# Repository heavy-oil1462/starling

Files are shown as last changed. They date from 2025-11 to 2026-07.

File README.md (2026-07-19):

# Starling

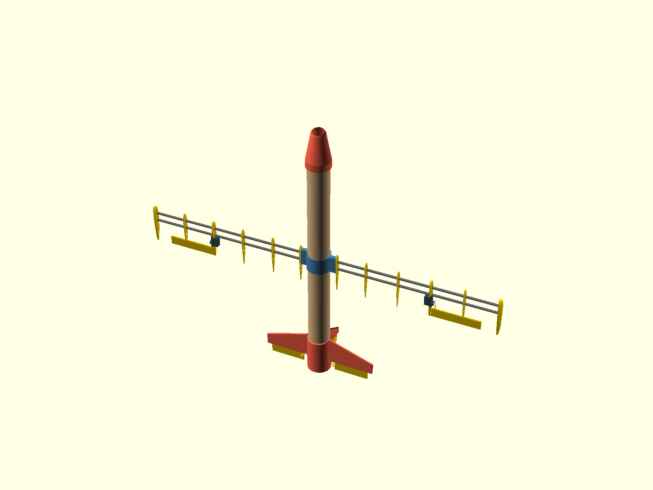
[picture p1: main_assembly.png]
Current assembly


**Starling** is an open-source, cheap, quick-to-assemble RC plane built around a paper tube. The fuselage is a ~53 mm postal tube; everything structural that isn't the tube is 3D printed or off the shelf. It is deliberately **not** built to last — it's built to be so cheap and fast to assemble that it can be treated as single-use for whatever job it's needed for (painting the tube adds some weather resistance if you want more than one flight).

## Project goals

1. **Cheap and expendable** — paper-tube fuselage, printed joints, hobby-grade electronics. Losing the airframe should not hurt.
2. **Payload modularity** — payloads ride *inside* the tube, not bolted to the outside. The tube is one uncut length, cut to suit the mission; a printed adapter wraps the payload so it slides into the tube bore (~47 mm) and can be positioned anywhere along it. A payload that is already a cylinder of the right diameter needs no adapter at all.
3. **Movable wing** — the wing mount slides along the tube to re-trim CG for whatever payload is fitted.
4. **Quick assembly** — parts slide over/into the tube; the goal is field-assembly speed, not workshop craftsmanship.
5. **ArduPilot brain** — flight controller config will live in this repo alongside the CAD (planned).

## Airframe

| Part | File | Notes |
|---|---|---|
| Fuselage | (bought, not printed) | 50 mm-class paper/postal tube, ~53 mm OD |
| Nose cone | `cad/nose.scad` | Sleeve-mounted, angled FPV camera opening |
| Wing adapter (trim rig) | `cad/wing_adapter.scad` | Reusable tooling: M3 belly clamp locks it anywhere along the tube while you find the CG for a payload |
| Wing adapter (flight) | `cad/wing_adapter_glue.scad` | Same wing interface, no hardware; slid to the documented station and tacked with hot-glue fillets at the rims (`docs/wing-stations.md`) |
| Wing ribs | `cad/wing_rib.scad`, `cad/wing_rib_servo.scad` | NACA airfoil ribs on 6 mm carbon spars, foam-board skin; all ribs sit outboard of the adapter tab, and the servo rib carries the aileron servo |
| Tail sleeve | `cad/tail.scad` | Prints upright, support-free: internal push-fit servo pockets, angled pushrod slots, fin sockets, rear motor mount (pusher) |
| Tail fins | `cad/tail_fin_horizontal.scad` (×2), `cad/tail_fin_vertical.scad` | Print flat (strongest orientation); root tabs glue into the sleeve's fin sockets |
| Control surfaces | `cad/control_surface.scad` | One part, three spans (elevator/rudder/aileron); tape-strip hinge in matching grooves |
| Calibration prints | `cad/calibration/` | Tube fit ring (OD), tube bore gauge (ID), motor screw pattern, servo pocket — print these first |

All servos mount internally — the tail servos sit high in the sleeve with angled wire slots, the aileron servos hide inside the wing with just the arm through the upper skin. Mechanical throw: ±32° tail / ±45° aileron vs ±25°/±20° targets — analysis in `docs/control-system.md`, checked by `scripts/throw_check.py`.

Print-ready STLs for every part are committed under `stl/`.

## Calibrate to your tube first

Postal tube varies between batches, and the paper wall varies more than the outside does — so the OD does not tell you the bore. Both are measured, and both gauges print as **three numbered variants at once**:

| Print | Measures | Set |
|---|---|---|
| `stl/tube_fit_ring.stl` | outside diameter — what sleeves slide over | `tube_od` |
| `stl/tube_bore_gauge.stl` | inside diameter — what plugs slide into | `tube_id` |

Print one, try all three variants on your actual tube, and read the number engraved on the one that fits best. Type those two numbers into `cad/design_params.scad`, re-run `scripts/regen_all.py`, and every sleeve and plug in `stl/` is now cut for your tube. If the winner is an end variant your tube is outside the bracket — set the value to that number and reprint the gauge to re-centre.

## Working on the CAD

Tooling is Python + OpenSCAD, fully headless, fetched via nix (no manual installs):

```bash
python3 scripts/regen_all.py            # gates + rebuild every STL + assembly render
python3 scripts/regen_all.py --stl-only # export everything printable to stl/
python3 scripts/check_params.py         # do the parts still fit the same tube?
python3 scripts/throw_check.py          # control-surface throw / slot / clearance check
python3 scripts/render_scad.py cad/nose.scad nose.png   # one-off render
```

`scripts/regen_all.py` is the single entry point for derived artifacts — the STLs and `main_assembly.png` are build products and regenerate with the CAD that changed them. Every dimension two parts share (tube OD, clearances, spar chain, servo/motor footprints, stations) lives in **`cad/design_params.scad`**; parts include it, and `check_params.py` fails the build if any file shadows a shared name — so the parts can never silently disagree about the tube they share.

## Status

Early prototype. Structural parts exist, print, and fit together on paper (see `docs/design-review.md` for the reviewed-and-fixed findings and the open follow-ups: measure your actual tube, pick the motor/prop combo). Wing skin build notes and the ArduPilot configuration are next.

## License

MIT, see [LICENSE](LICENSE).

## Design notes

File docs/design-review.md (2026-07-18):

# Design review — 2026-07-16

Reviewed by rendering every part headlessly (`scripts/regen_all.py`) and inspecting the assembly render. **Update (same day): all findings below are fixed or explicitly documented** — each item now carries a status. The enabling change is `cad/design_params.scad`: a single shared parameter file every part includes, enforced by `scripts/check_params.py`, which fails if any file re-declares a shared name — so interface mismatches can no longer exist silently.

## Fit-critical (parts would not have gone together as drawn)

1. **The tube diameter was defined five times with four different values** (52.9–52.95 across fuselage, nose, tail, wing adapter, fit ring).
   **Fixed:** one `tube_od` (52.95 — verify against your actual tube with the fit ring) plus `sleeve_clearance` in `design_params.scad`; every sleeve bore derives from them. Shadowing a shared name now fails `check_params.py`.

2. **Wing adapter tab (11 mm) ≠ rib adapter slot (15 mm).**
   **Fixed:** both sides now derive from the shared `wing_tab_thickness` (11); the root-rib window is `wing_tab_thickness + fit_tol` by construction.

3. **The rib's adapter/foam slots were declared but never cut.**
   **Fixed (adapter):** first via a windowed root rib that slid over the tab; superseded same day — ribs now simply sit *outboard* of the tab tip (first station 47 > tab tip 44.5), so no rib ever overlaps the adapter, and panel alignment comes from the bonded spar rods.
   **Removed (foam):** the foam-skin slots were geometrically impossible — a 5 mm skin cannot be inlaid into a ~15 mm-thick section — so the dead parameters are gone and the design intent is documented in `wing_rib.scad`: the skin *wraps* the ribs; the rib profile is the inner mold line.

4. **The tail's internal rim (tube stop) was declared but never modeled**, letting the tube slide into the servo bodies.
   **Fixed:** the rim is now modeled (top edge at shared `tail_tube_stop = 54`, above the servo bay at z≈4–36) and `main_assembly.scad` seats the tube on the same shared value. Verified in a cutaway render.

## Structural concerns

5. **Wing spar engagement was 10 mm of blind socket in a printed tab.**
   **Improved:** sockets now run through the tab and deep into the sleeve wall, stopping on a 1 mm floor at the bore (~17 mm engagement — a first through-wall version let the rod poke into the bore and press on the paper tube, which would have blocked the CG slide; caught and fixed). `wing_adapter.scad` documents that rods must be bonded in for flight — sockets are alignment, not structure. A continuous over/under-tube spar remains the upgrade path if flight testing shows the joint working loose.

6. **The wing adapter had no clamp** (CG-trim slide was friction-only at the highest-load joint).
   **Fixed:** belly slit + M3 lug pair (two screws) so the adapter locks anywhere along the tube. Nose and tail sleeves stay friction/tape fits — they carry far smaller loads and tape suits the expendable philosophy.

7. **"Living hinge" fins in PLA would crack within dozens of cycles.**
   **Documented as intent:** the TE slit is a *groove for a taped/glued-in hinge* (foam or hinge strip), not a printed living hinge — stated in `tail.scad` where the slit parameters live.

8. **Pusher prop vs control surfaces**: the prop disc sits immediately behind the fin trailing edges.
   **Resolved by geometry + gated:** the fins are now shortened by `ctrl_chord + 2`, so the control surfaces live in that gap and their TE sits 2 mm *forward* of the motor face at neutral — deflection only increases the clearance. `scripts/throw_check.py` (run by `regen_all.py`) documents the residual rule: keep ≥5 mm between motor face and prop disc. Full analysis: `docs/control-system.md`.

## Geometry / code health

9. **Assembly rib row didn't line up with the adapter** (magic numbers 251/300, no spars modeled).
   **Fixed:** `main_assembly.scad` rewritten — everything derives from `design_params.scad` (`wing_station`, `tail_tube_stop`, spar chain), spar rods are modeled, the root rib sits on the tab, and the whole wing group moves with one number. The render is now an actual fit check.
10. **Nose camera hole placed by a cone-section formula extrapolated past its valid range.**
    **Fixed:** the opening is bored outward from the tip-sphere center along the flight axis, tilted `camera_hole_angle_degrees` toward the belly — anchored to the tip so it survives reshaping the cone.
11. **`fuselage.scad` coincident faces** (inner cutter same height as outer).
    **Fixed:** cutter extended past both ends; the file is also now marked as a visual model of the bought tube (no STL is exported for it).
12. **`$airfoil_fn`/`$close_airfoils` special-variable warnings** (top-level `$var` assignments are invisible to `use<>` consumers).
    **Fixed:** plain variables, closed-TE constant baked in; assembly renders with zero warnings.
13. **Comment drift** ("symmetric" on the cambered 2415, unmeasured paper wall).
    **Fixed/consolidated:** NACA comment corrected; `tube_wall` lives once in `design_params.scad` with a note to measure the real tube.

## Good bones (kept)

- The sleeve/plug-on-a-tube architecture, the calibration-print habit, the single-print tail with wall-pocketed servos, and NACA 2415 at 100 mm chord — all solid choices, now all fed from the shared parameter file.

## Remaining follow-ups

- Measure the real tube: print `tube_fit_ring` and `tube_bore_gauge`, and set `tube_od`/`tube_id` from the best-fitting variant of each. Repeat per tube batch.
- Pick the motor/prop combo and verify prop-vs-elevator clearance (finding 8).
- If flight tests show the bonded spar joints loosening, design the continuous-spar variant of the adapter (finding 5's upgrade path).

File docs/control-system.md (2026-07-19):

# Control system — servos, linkages, throw

Design decided 2026-07-16. Numbers below are computed by `scripts/throw_check.py`
from `cad/design_params.scad` (re-run it after changing any horn/travel/slot
parameter — `regen_all.py` runs it as a gate).

## Layout: servos INSIDE, only a slot in the airstream

All five servos are 9 g (SG90-class) and all mount *internally*, with a wire
pushrod exiting through a small slot to the control horn:

The wire always attaches at the **tip of the full-length servo arm**, and at
neutral the arm sits **perpendicular to the wire** — that is where the
linkage is most linear and transmits the most motion.

- **Tail (elevator ×2, rudder ×1)** — each servo lies on its side, shaft
  tangential, and **presses into a snug printed pocket** (walls grip the
  outer 6 mm of the body on both ends and the side away from the shaft; a
  drop of CA is optional and the tube, once installed, boxes the servos in
  radially). Three 22 mm bodies cannot share one height in the Ø53 bore, so
  they are **Z-staggered**: the two elevator servos sit HIGH (`tail_servo_z`,
  opposite sides — their bodies coexist, reaching past the rim into the
  hollow tube interior on a narrowed tower), the rudder servo sits LOW
  (`tail_rudder_z`, arm swinging just above the motor plate). The pockets
  stand as **columns on the motor plate** with 45°-sloped ceilings, so the
  sleeve prints upright with zero supports. Each wire rakes outboard through
  an **angled wall slot** aligned with its run — elevators down-aft at 42°,
  rudder up-forward at 56°. The outer surface carries nothing but those
  slots and the three fin-socket bosses.
- **Wing (aileron ×2)** — the servo mounts to a dedicated **servo rib**
  (`cad/wing_rib_servo.scad`): an open-bottom bay aft of the rear spar takes
  the body, and the servo's flange seats on the rib's outboard face (CA/
  strapping tape; the rib itself is bonded to spars and skin, so the servo
  reacts against real structure — an earlier spar-clip cradle was dropped
  because printed clips on smooth carbon rod rotate, creep, and pry open
  under wire loads). The servo rib is not an extra station: it **replaces
  the standard rib** at its place in the row. The aileron root starts just
  outboard of it; the arm pokes through a small slot in the **upper** skin
  (low-pressure side) and a short wire links to the aileron's up-turned horn
  just above the wing. A 9 g servo stands ~3 mm proud of the LOWER skin at
  the bay (the aft bay of a 15 %/100 mm section is thinner than the servo) —
  fair it with tape, or use a 5 g servo which fits flush. Rib cable holes
  carry the lead inboard.

## Control surfaces

`cad/control_surface.scad` — one printed part, three sizes (span is a module
parameter): elevator 88, rudder 60, aileron 120 mm; chord 22 mm, tapering
4 → 1.2 mm. The tail fins are shortened by `ctrl_chord + 2` so the surfaces
fill the gap without ever crossing the motor-face plane.

**Tail hinge**: the fin TE and the surface LE both carry a 1.6 × 2.5 mm
groove; a flexible strip (fiber tape folded, or 0.5 mm PP sheet) glues into
both. Printed living hinges crack within dozens of cycles — the strip
doesn't, and it suits the expendable-airframe idea (surfaces survive, tube
doesn't).

**Aileron mounting**: the aileron nests *inside* the wing planform — rib
stations under its span use the TE-cropped rib (`cad/wing_rib_aileron.scad`,
cut at the hinge line + 2 mm), so the surface fills a notch in the TE rather
than hanging behind it. There is no printed wing TE to carry a matching
groove, so the aileron hinges on **plain tape along the top surface**: the
top skin ends at the crop line, tape spans from skin onto the aileron's top
face (the aileron top sits a few mm below the skin surface — the tape
bridges the step; add a second strip on top after checking throw). The 2 mm
crop gap clears the 4 mm LE face swinging under the tape pivot to past
±25°, comfortably over the ±20° target. The aileron's printed LE groove
(shared part with the tail) is simply unused.

## How much throw actually exists

A 9 g servo arm can sweep ~180° total, but only ~±45° of it is usable: past
that the arm approaches parallel with the wire and the linkage goes nonlinear
and finally binds (never program past ~±60°). With the wire on the arm tip
(`servo_horn_r = 10`), `servo_travel_deg = 45`, and a 1:1 control horn
(`ctrl_horn_r = 10`):

| step | value |
|---|---|
| arm tip ±45° × 10 mm | **±7.1 mm** at the wire |
| elevators (high servos): wire raked 42° | × 0.74 → **±31.7°** |
| rudder (low servo): wire raked 56° | × 0.56 → **±23.3°** |
| wing: direct link, no rake | **±45°** aileron |
| targets | elevator ±25°, rudder ±20°, aileron ±20° |
| slot channel needed | 2 × 7.1 + 1.2 wire + 2 margin = 17.3 → **18 mm**, angled with the wire |

The rake factor is the price of keeping the servos inside the tube —
cos(rake) of the wire motion becomes horn motion. The rudder pays the most
because its low, staggered position stretches the radial run, which is fine:
with ailerons fitted the rudder only coordinates turns (hence its ±20°
target). Trim the excess with transmitter endpoints/expo (or ArduPilot
SERVOx limits), which also softens 9 g centering slop. The rudder arm dips
to z≈5 at full ±45° — 1 mm above the motor plate — so never program it past
±40°.

**Prop clearance (pusher):** at neutral the tail surfaces' TE sits 2 mm
forward of the motor face; deflection only rotates the TE *away* from it.
Clearance to the prop disc is therefore set by the motor's own shaft length —
keep ≥5 mm between the motor face and the prop disc, which any 22xx with a
normal prop adapter provides.

## Open items

- The aileron servo's arm slot in the upper foam skin (~4 × 20 mm) is cut at
  build time — mark it from the mount position before skinning.
- Wire ends: Z-bend at the servo arm tip, and a Z-bend or micro linkage
  stopper at the control horn (nothing printed needed).
- Rudder + both elevators use identical geometry; differential/mixing is a
  software (ArduPilot) concern, not a mechanical one.

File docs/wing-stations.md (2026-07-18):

# Wing stations — trim once, replicate by the numbers

The movable wing exists to re-trim CG per payload, but only the FIRST
airframe of a configuration needs to move. The workflow:

1. **Trim** on the clamping adapter (`cad/wing_adapter.scad` — tooling,
   lives in the kit box). Fit the payload, slide the wing, glide-test,
   repeat. The M3 clamp makes every guess reversible.
2. **Record** the winning station in the table below. If it's the
   configuration currently being built, also set `wing_station` in
   `cad/design_params.scad` so the assembly render matches reality.
3. **Replicate**: every later airframe of that configuration flies the
   hardware-free `cad/wing_adapter_glue.scad`. Mark the fresh tube, slide
   the adapter to the mark, tack it with hot-glue fillets at both rims
   (each rim has a chamfered glue seat).

Fillets at the rims only — never glue in the bore. Rim tacks cut free
cleanly, so a bad guess or a spent tube gives the printed adapter back;
bore glue makes the adapter consumable.

## Marking a fresh tube

Stations are measured from the **motor face**, but a tape measure works
from the tube's rear end. The tube seats `tail_tube_stop` deep against the
tail sleeve's internal rim, so:

```
mark = wing_station − tail_tube_stop     (mm, from the REAR end of the tube)
```

The adapter's **aft edge** sits on the mark. With the current defaults:
300 − 54 = **246 mm**.

## Documented stations

| Payload | Mass (g) | `wing_station` (mm from motor face) | Mark (mm from rear tube end) | Notes |
|---|---|---|---|---|
| _none yet — trim the bare airframe first_ | | 300 (untrimmed default) | 246 | |

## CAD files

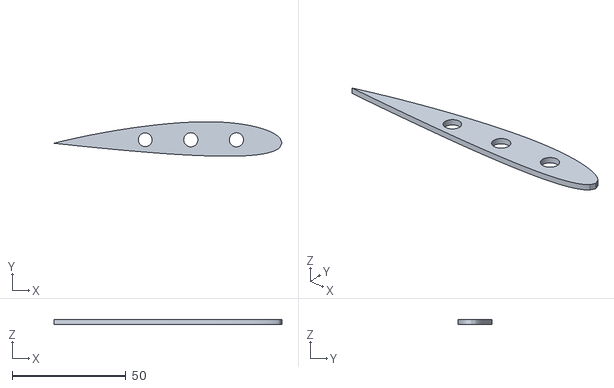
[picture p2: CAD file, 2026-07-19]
stl/wing_rib.stl
100.0 x 15.1 x 2.00

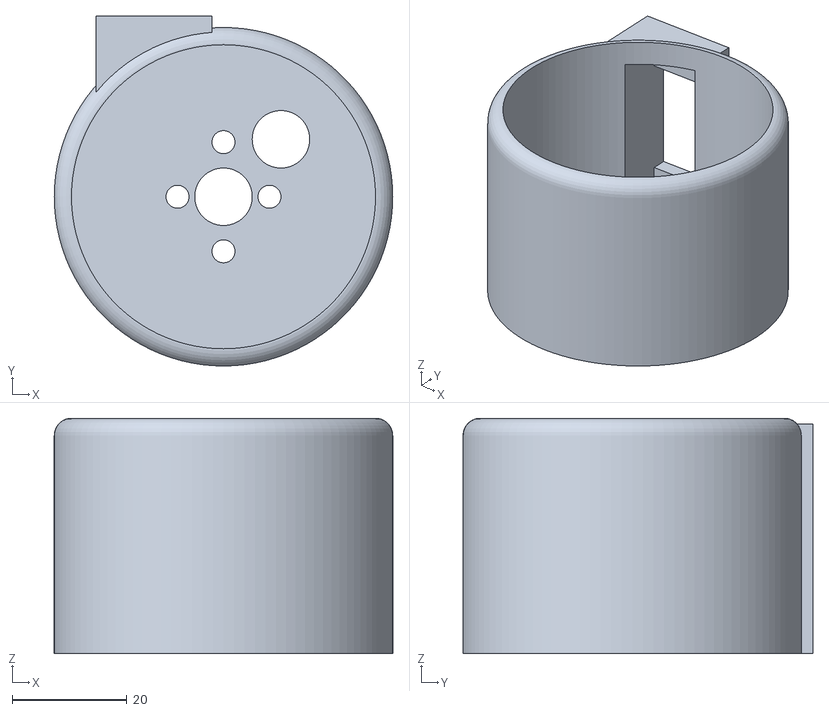
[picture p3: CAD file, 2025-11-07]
test.stl
58.9 x 60.9 x 41.0

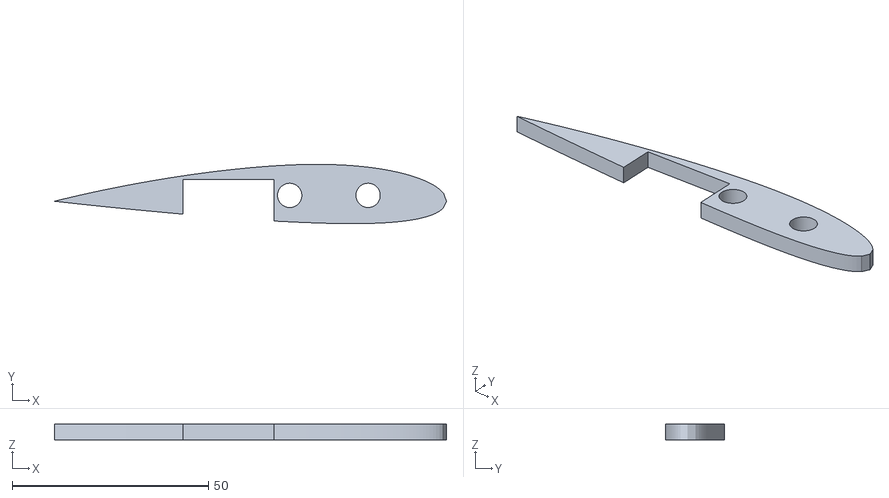
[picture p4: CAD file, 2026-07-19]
stl/wing_rib_servo.stl
100.0 x 15.1 x 4.00

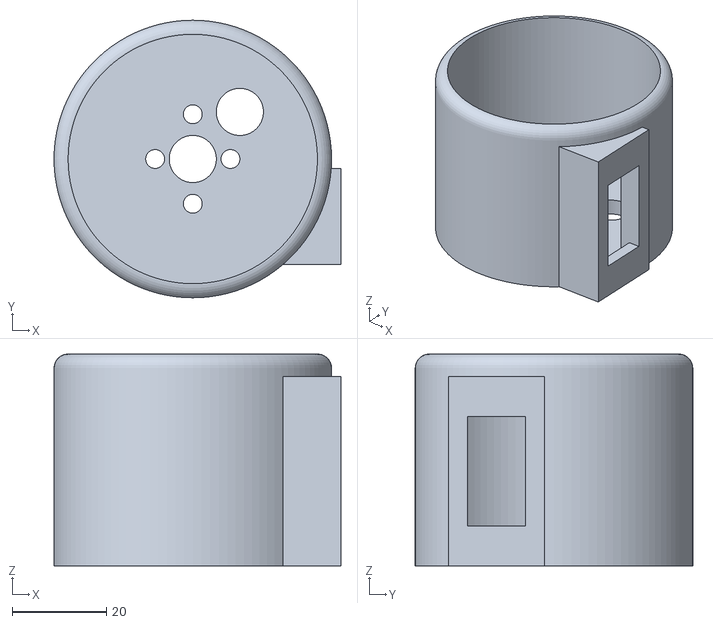
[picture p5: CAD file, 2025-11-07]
testthing.stl
60.9 x 59.0 x 45.0

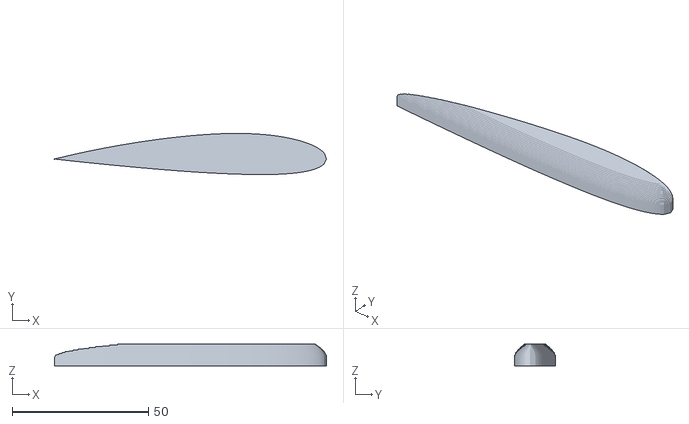
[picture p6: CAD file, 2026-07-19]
stl/wing_rib_tip.stl
100.0 x 15.1 x 8.02

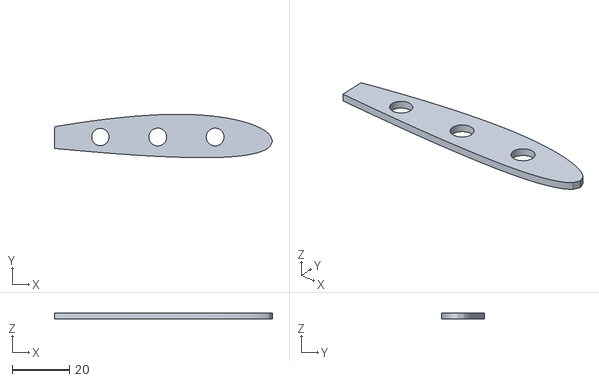
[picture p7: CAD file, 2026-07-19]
stl/wing_rib_aileron.stl
76.0 x 15.1 x 2.00

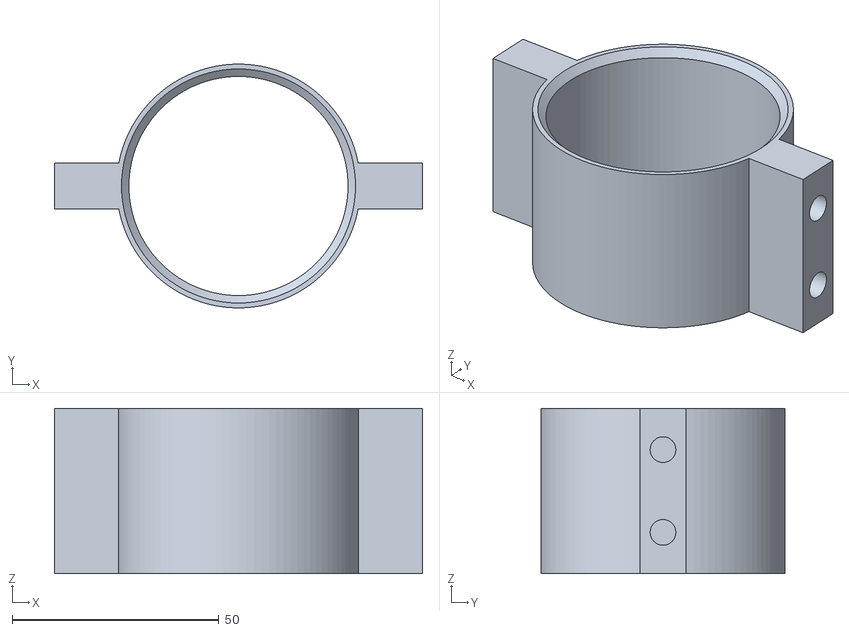
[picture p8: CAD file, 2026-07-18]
stl/wing_adapter_glue.stl
89.0 x 59.0 x 40.0

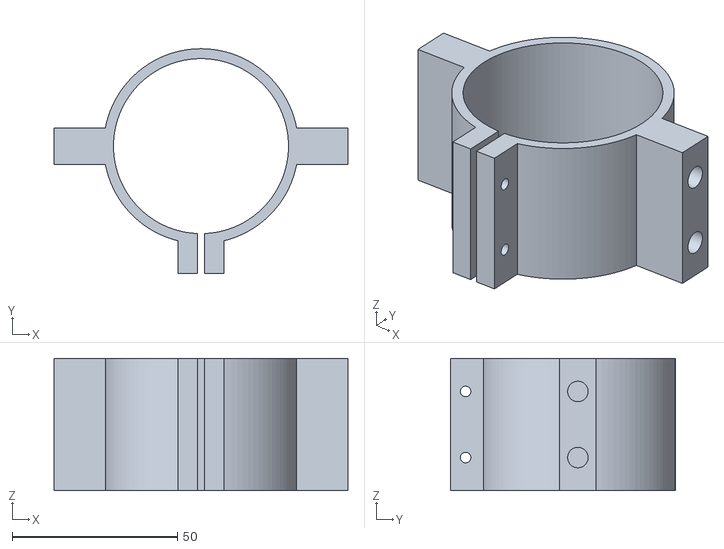
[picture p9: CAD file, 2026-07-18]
stl/wing_adapter.stl
89.0 x 68.0 x 40.0

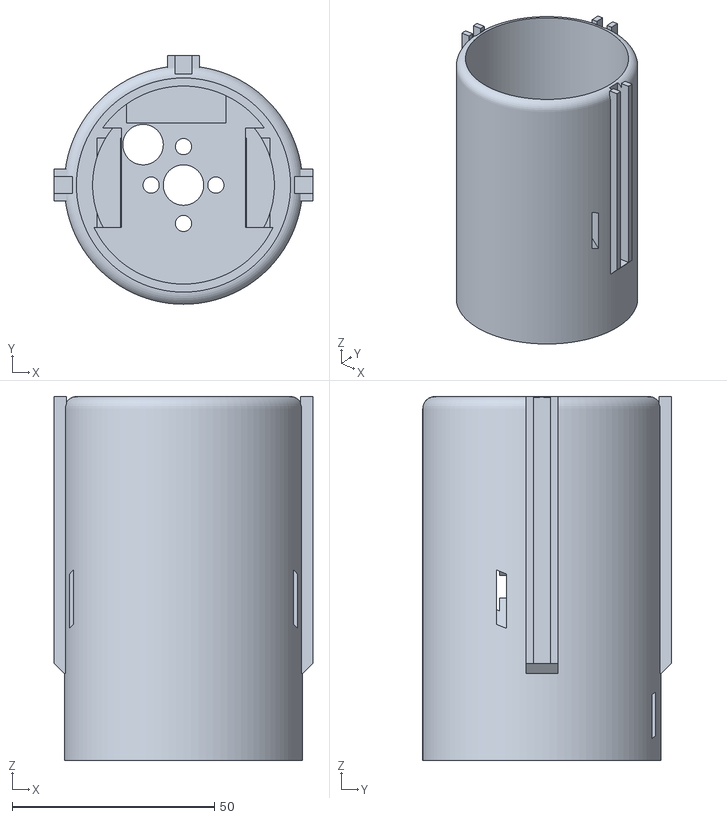
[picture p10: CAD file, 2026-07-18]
stl/tail.stl
64.0 x 61.5 x 90.0

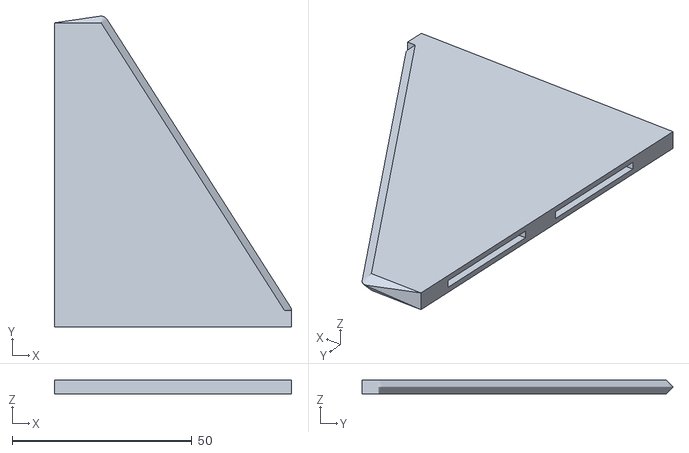
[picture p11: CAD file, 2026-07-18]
stl/tail_fin_vertical.stl
66.0 x 86.5 x 4.00

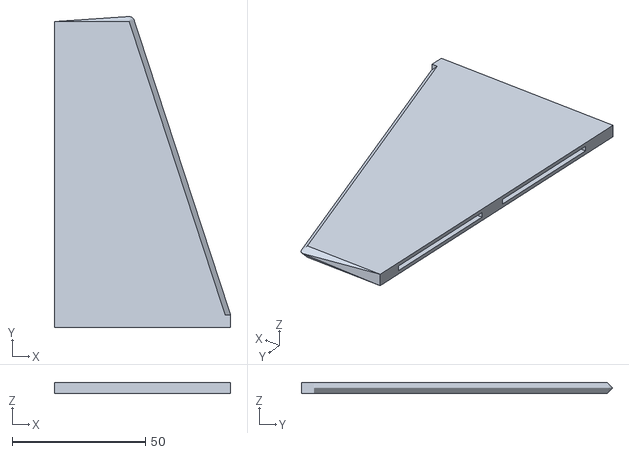
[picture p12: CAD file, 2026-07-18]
stl/tail_fin_horizontal.stl
66.0 x 116.5 x 4.00

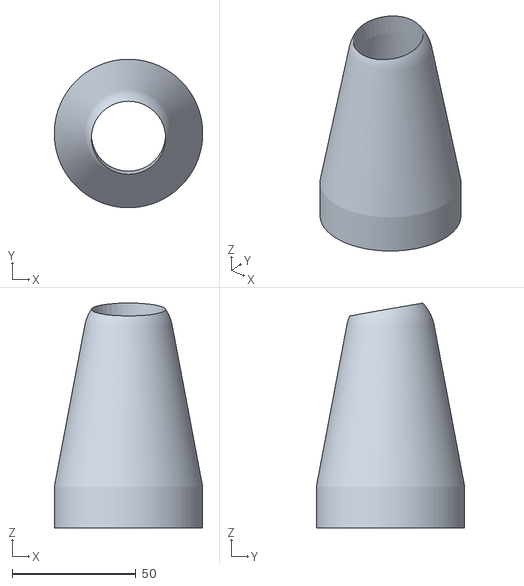
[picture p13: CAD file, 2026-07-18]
stl/nose.stl
60.0 x 60.0 x 90.9

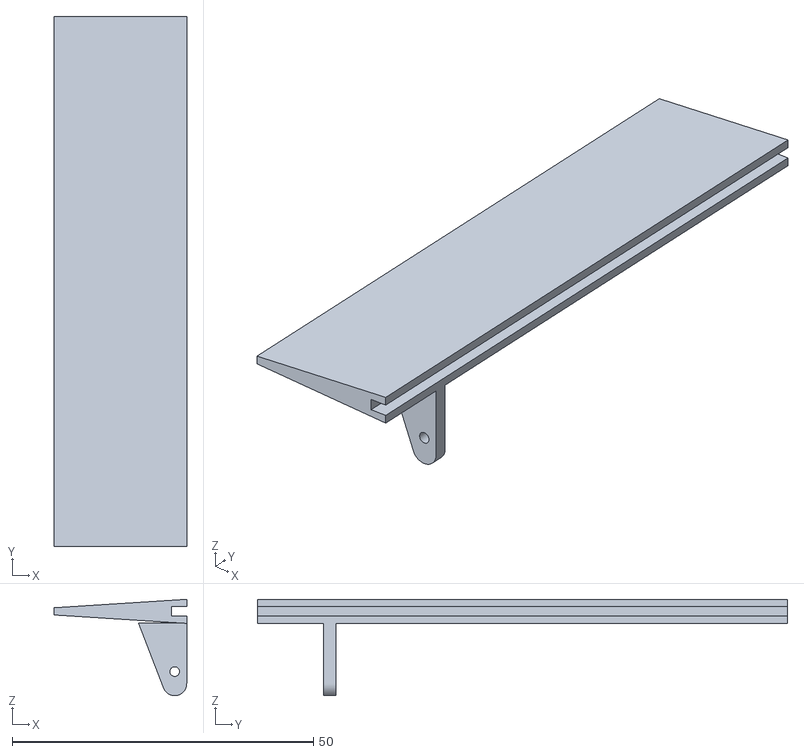
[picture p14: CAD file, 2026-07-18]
stl/control_surface.stl
22.0 x 88.0 x 16.0

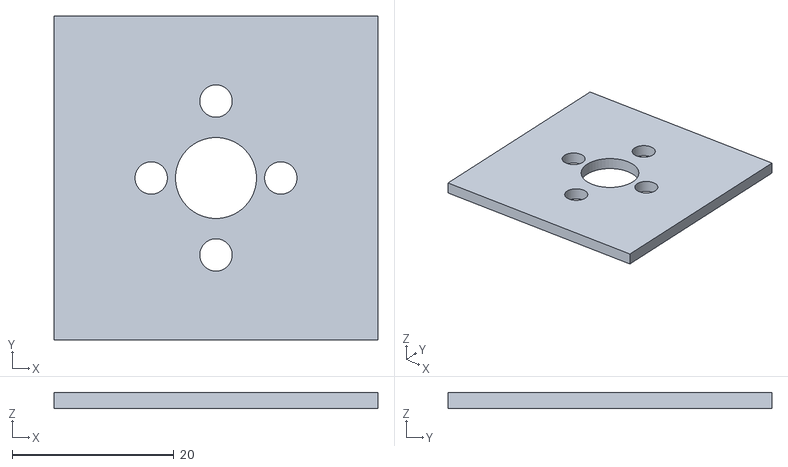
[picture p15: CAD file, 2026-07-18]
stl/motor_mount_test.stl
40.0 x 40.0 x 2.00

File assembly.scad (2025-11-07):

use <tail.scad>
use <spar.scad>
use <adapter.scad>
use <nose.scad>
use <fuselage.scad>

$fn=100;

translate([0, 0, 50]) fuselage();

for (i = [50, 150, 250, 350, 420]) {
    rotate([0, -90, 0]) 
        translate([251, 0, i]) 
            wing_rib_with_cutouts();
}

for (i = [-50, -150, -250, -350, -420]) {
    rotate([0, -90, 0]) 
        translate([251, 0, i]) 
            wing_rib_with_cutouts();
}

translate([0, 0, 300]) 
    wing_adapter();

rotate([0, 0, 180]) 
    translate([0, 0, 565]) 
        cone_housing();

tail_assembly();

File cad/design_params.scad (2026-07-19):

// ============================================================
// STARLING SHARED DESIGN PARAMETERS — single source of truth for
// every dimension two parts must agree on.
//
// Consumers:
//   - every part in cad/ does        include <design_params.scad>
//   - parts in cad/calibration/ do   include <../design_params.scad>
//   - scripts/check_params.py FAILS the build if any of these names
//     is re-declared anywhere else — change values HERE only.
//
// Keep this file to simple `name = value;` lines so the tooling can
// parse it. One-off experiments: `openscad -D name=value` beats the
// include, no need to edit this file.
// ============================================================

// --- The paper tube (bought part, consumable) ---
// BOTH diameters are measured, not derived from a nominal wall thickness:
// paper wall varies batch to batch, so the OD does not predict the bore.
// Print the two calibration gauges with every new batch of tube, and type
// the number engraved on the best-fitting variant in here.
tube_od     = 52.95;   // sleeves slide OVER this — cad/calibration/tube_fit_ring.scad
tube_id     = 46.95;   // plugs slide INTO this  — cad/calibration/tube_bore_gauge.scad
tube_length = 540;

// --- Printed-part fits ---
sleeve_clearance = 0;   // added to every sleeve bore diameter; tune via the fit ring
plug_clearance   = 0;   // subtracted from every plug OD; tune via the bore gauge
fit_tol          = 0.2; // clearance for printed slots/pockets
sleeve_wall      = 3;   // wall thickness of printed sleeves

// --- Wing spar chain (rib holes = adapter sockets = carbon rods) ---
spar_rod_d    = 6;     // carbon rod diameter
spar_hole_d   = 6.2;   // printed hole for that rod
spar_spacing  = 20;    // chordwise distance between the two spars
spar_y_offset = 1.5;   // spar line sits this far above the rib chord line

// --- Wing geometry ---
rib_chord     = 100;
naca_code     = 2415;  // cambered lifting section
rib_thickness = 2;
tip_spar_socket = 6;   // blind spar-socket depth in the tip rib; the spar
                       // rods are cut so they END inside these sockets, so
                       // the assembly's spar length derives from this too

// --- Wing adapter <-> root rib interface ---
wing_tab_thickness = 11; // adapter tab (socket carrier; ribs sit outboard of it)
wing_tab_span      = 15; // how far the tab reaches out from the sleeve
adapter_length     = 40; // sleeve length = tab chord extent

// --- Stations along the tube (assembly; wing slides for CG trim) ---
wing_station       = 300; // wing adapter position, measured from the motor face
tail_tube_stop     = 54;  // tube bottoms out here inside the tail sleeve (rim top)
nose_sleeve_length = 20;  // how far the nose cone slides over the tube

// --- Servos (9 g / SG90 class) ---
servo_body   = [23, 12.2]; // [length, width]
servo_flange = [32, 12.2];
servo_height = 22;         // body height incl. shaft boss, without horn

// --- Control system (internal servos, wire pushrods through wall slots) ---
ctrl_chord       = 22;   // control-surface chord (elevator / rudder / aileron)
ctrl_thickness   = 4;    // control-surface root thickness = fin thickness
hinge_groove_w   = 1.6;  // groove for the hinge strip/tape, both fin TE and surface LE
hinge_groove_d   = 2.5;
pushrod_d        = 1.2;  // piano-wire pushrod, attached at the TIP of both arms
pushrod_slot_w   = 2.5;  // wall slot the pushrod moves in
pushrod_slot_len = 18;   // slot channel length along the rod (see throw_check.py)
servo_horn_r     = 10;   // full arm length — the wire connects at the far end
servo_travel_deg = 45;   // used one-sided travel; the arm can do ~±90 (180 total)
                         // but the linkage stays near-linear only within ±45
ctrl_horn_r      = 10;   // control-surface horn = servo horn -> 1:1 linkage

// Tail linkage geometry. Three 22 mm-wide servos cannot share one height
// inside the Ø53 bore (corner collisions), so they are STAGGERED in Z:
// the two elevator servos sit HIGH (opposite sides, they coexist), the
// rudder servo sits LOW. Each wire attaches at the arm tip and exits
// through an angled wall slot raked toward its surface horn.
tail_servo_z           = 33; // bottom (shaft end) of the ELEVATOR servo bodies
tail_slot_angle        = 42; // elevator rod angle off the fuselage axis
tail_rudder_z          = 9;  // bottom (shaft end) of the RUDDER servo body
tail_rudder_slot_angle = 56; // rudder rod angle off the fuselage axis

// --- Motor (22xx class, rear pusher) ---
motor_shaft_hole_d = 10;
motor_screw_hole_d = 4;
motor_pattern_x    = 16;  // screw pattern
motor_pattern_y    = 19;

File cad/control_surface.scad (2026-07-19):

// ==============================================================================
//   CONTROL SURFACE — printed flap for elevator, rudder, or aileron.
//
//   Local frame: hinge line = Y axis (span along +Y), chord extends -X (aft),
//   thickness centered on Z. The LE face carries a hinge groove matching the
//   groove in the fin trailing edges: a flexible strip (fiber tape / 0.5 mm
//   PP) glues into both grooves and is the hinge — printed living hinges
//   crack, this doesn't. The AILERONS hinge on plain tape to the top skin
//   instead (no printed wing TE to carry a groove); their LE groove is
//   simply unused. See docs/control-system.md.
//
//   The control horn is integrated near the root; the pushrod hooks into its
//   hole at ctrl_horn_r from the hinge line. Print flat, horn up, with a dab
//   of support under the horn (or slice horn-side down and accept the seam).
//
//   Default render = elevator (span 88). Other sizes are module parameters —
//   the assembly instantiates rudder (60) and aileron (120) variants.
// ==============================================================================

include <design_params.scad>

$fn = 60;

// horn_up: flips the horn to the +Z side of the surface — used by the
// ailerons, whose linkage lives ABOVE the wing (low-pressure side).
module control_surface(span = 88, horn_pos = 12, with_horn = true, horn_up = false) {
    te_thickness = 1.2;

    difference() {
        union() {
            // Tapered flap: full thickness at the hinge, thin TE
            rotate([90, 0, 0])   // build profile in X-Z, extrude along span
                translate([0, 0, -span])
                    linear_extrude(height = span)
                        polygon([
                            [0,            ctrl_thickness / 2],
                            [0,           -ctrl_thickness / 2],
                            [-ctrl_chord, -te_thickness / 2],
                            [-ctrl_chord,  te_thickness / 2],
                        ]);

            // Control horn: a blade in the X-Z plane, pushrod hole at
            // ctrl_horn_r from the hinge line
            if (with_horn)
                translate([0, horn_pos, 0])
                    mirror([0, 0, horn_up ? 1 : 0])
                        horn();
        }

        // Hinge groove along the LE face (mirror of the fin TE groove)
        translate([-hinge_groove_d, -0.1, -hinge_groove_w / 2])
            cube([hinge_groove_d + 0.1, span + 0.2, hinge_groove_w]);
    }
}

module horn() {
    hole_d = pushrod_d + 0.4;
    difference() {
        hull() {
            translate([-8, -1, -ctrl_thickness / 2])
                cube([8, 2, 0.1]);
            translate([-2, 0, -(ctrl_horn_r + 2)])
                rotate([90, 0, 0])
                    cylinder(h = 2, d = 4, center = true);
        }
        translate([-2, 0, -ctrl_horn_r])
            rotate([90, 0, 0])
                cylinder(h = 3, d = hole_d, center = true);
    }
}

control_surface();

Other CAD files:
stl/tube_fit_ring.stl
stl/servo_mount_test.stl
cad/servo_9g.scad
cad/archive/cone_v1.scad
cad/archive/tail_v1.scad
cad/calibration/motor_mount_test.scad
cad/calibration/servo_mount_test.scad
cad/calibration/tube_bore_gauge.scad
cad/calibration/tube_fit_ring.scad
cad/fuselage.scad
cad/main_assembly.scad
cad/nose.scad
cad/tail.scad
cad/tail_fin_horizontal.scad
cad/tail_fin_vertical.scad
cad/wing_adapter.scad
cad/wing_adapter_glue.scad
cad/wing_rib.scad
cad/wing_rib_aileron.scad
cad/wing_rib_servo.scad
cad/wing_rib_tip.scad

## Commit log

2025-11-07 Initial design work
    Squash of the early prototype commits (November 2025 to January 2026)
    that had placeholder messages.
    [adapter.scad, adapter.stl, assembly.scad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]
2026-07-18 Organize repo into cad/scripts/stl layout with headless nix tooling
    - cad/: renamed parts to what they are (spar.scad was the wing rib,
    adapter.scad the wing adapter); calibration prints under
    cad/calibration/; dead versions under cad/archive/
    - scripts/: render_scad.py (headless OpenSCAD via nix + Mesa EGL),
    check_params.py (cross-file interface-dimension gate),
    regen_all.py (single pipeline: params -> STLs -> assembly render)
    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
    [adapter.stl, cone_v1.scad, fuselage.scad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]
2026-07-18 Fix all design-review findings; single-source params in design_params.scad
    - cad/design_params.scad: every shared dimension lives here; all parts
    include it. check_params.py now FAILS if any file shadows a shared
    name, so interface mismatches cannot recur.
    - wing_adapter: rod sockets through tab + sleeve wall (~19mm engagement,
    bond rods), belly slit + M3 lug clamp for the CG-trim slide
    - wing_rib: root-rib variant with through-window for the adapter tab
    (new stl/wing_rib_root.stl); impossible foam-slot params removed and
    intent documented; $-special airfoil vars replaced (zero warnings)
    - tail: internal tube-stop rim modeled (protects the servo bay), motor
    pattern/servo footprin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
    [design_params.scad, fuselage.scad, fuselage.stl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]
2026-07-18 Control system: internal servos, wire linkages, printed surfaces; spar socket fix
    - wing_adapter: rod sockets stop on a 1mm floor above the bore (~17mm
    engagement) — the through-wall version let the spar poke inside the
    adapter and press on the paper tube, blocking the CG slide
    - tail: external servo blisters/pockets replaced by INTERNAL locating
    pads + 2.5x18mm pushrod wall slots (only the slot meets the airflow);
    fins shortened by ctrl_chord+2 so surfaces never cross the motor face
    - new printed parts: control_surface.scad (one part, elevator/rudder/
    aileron spans, tape-strip hinge grooves) and wing_servo_mount.scad
    (snap-clips onto both spars, servo inboard inside the wing)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
    [control_surface.scad, control_surface.stl, design_params.scad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]
2026-07-18 Rework control linkages: arm-tip attachment, angled tail slots, direct wing links
    Per review feedback — the wire connects at the FAR END of the full-length
    servo arm (~180deg sweep, ~+/-45 usable) and the rod angle to the surface
    now drives the geometry:
    - tail: servos moved HIGH in the sleeve (tail_servo_z), arm perpendicular
    to the wire at neutral; the wall slots are now ANGLED channels aligned
    with the wire's 42deg rake down/outboard to the surface horn; pads
    capped below the tube stop
    - wing: servo mount moved outboard so the aileron sits directly behind
    it; the arm pokes through a slot in the UPPER skin (low-pressure side)
    and a short wire links to the aileron's up-turned h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
    [control_surface.scad, control_surface.stl, design_params.scad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]
2026-07-18 Wing servo moves to a servo rib; ribs no longer overlap the adapter
    - the spar-clip servo cradle is gone: printed C-clips on smooth carbon
    rod rotate, creep spanwise, and wire loads pry the mouths open. The
    aileron servo now mounts to a dedicated SERVO RIB (wing_rib_servo):
    open-bottom bay aft of the rear spar takes the body, flange seats on
    the rib's outboard face — the servo reacts against structure that is
    already bonded to spars and skin. 9g servos stand ~3mm proud of the
    lower skin there (documented; 5g fits flush), arm still exits the
    upper skin to the aileron horn, wire unchanged (direct, 1:1).
    - the windowed root rib is gone: the innermost rib now sits OUTBOARD of
    t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
    [design_params.scad, main_assembly.scad, wing_rib.scad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]
2026-07-18 Mirror the left elevator linkage; thicken the servo rib to 4mm
    - the left tail linkage was a 180deg ROTATION of the right one, which
    flipped its surface horn to the top of the fin while the printed slot
    stayed on the belly (seen from behind: slot under the fin, rod out the
    top). The left elevator pad, slot, and assembly control block are now
    true MIRRORS of the right — both elevator linkages sit on the belly.
    - wing_rib_servo now prints 4mm thick (standard ribs stay 2mm): it
    reacts the whole servo/linkage load until the skin adds stiffness.
    wing_rib_with_cutouts() gained a thickness parameter; servo seat and
    linkage plane shifted 1mm outboard to match.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
    [main_assembly.scad, tail.scad, tail.stl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]
2026-07-18 Connect the wing pushrod to the servo arm tip
    The aileron wire (and the aileron horn) sat 6.3mm outboard of the servo
    arm plane — the arm-tip position was estimated instead of derived. The
    arm plane actually lands 9.2mm outboard of the servo-rib station (flange
    seat + shaft boss + horn plate); wire and horn_pos now derive from that,
    so the linkage is closed and stays closed if wing_servo_station moves.
    [main_assembly.scad]
2026-07-18 Tail servos: Z-staggered push-fit pockets (they were colliding)
    All three tail servos sat at the same height; any two bodies 90deg apart
    interpenetrated at the corners — three 22mm-wide servos cannot share one
    height in a D53 bore. Per review feedback:
    - Z-stagger: elevator servos HIGH (tail_servo_z=33, opposite sides so
    they coexist; bodies reach past the rim into the hollow tube interior),
    rudder servo LOW (tail_rudder_z=9, arm swinging just above the motor
    plate, full-travel dip clears it by 1mm)
    - solid push-fit mounts: the shallow 1.2mm glue recess is now a snug
    pocket (0.15 allowance) whose walls grip the outer 6mm of the body on
    three sides, open toward the shaft so the a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
    [design_params.scad, main_assembly.scad, tail.scad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]
2026-07-18 Split the tail for support-free printing; fix servo pocket printability
    One-piece upright printing was impossible: the fins' straight horizontal
    trailing edges are full-span overhangs in any orientation (and upright
    fins would snap along layer seams). The tail is now three support-free
    parts:
    - tail sleeve (tail.stl): prints UPRIGHT on the motor face. Fin sockets
    = vertical grooves in chamfered external bosses (~4.5mm glued tab
    engagement, 1mm of wall kept under each groove); internal rim gains a
    45deg chamfer underneath
    - fins (tail_fin_horizontal x2 / tail_fin_vertical): print FLAT — no
    supports, layer lines along the span (the strong direction), root tab
    drops into the socket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
    [design_params.scad, main_assembly.scad, tail.scad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]
2026-07-18 Calibrate to the tube with numbered gauge variants; measure the bore
    The tube is a bought consumable and varies between batches, and the paper
    wall varies more than the outside does — so tube_od does not predict the
    bore that payload adapters and other plugs have to fit.
    Both diameters are now measured. Each gauge prints three variants at once,
    engraved with the dimension it embodies; you try them on the real tube and
    type the winning number straight into design_params.scad.
    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
    [design_params.scad, fuselage.scad, tail.scad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]
2026-07-18 Correct the payload interface: payloads plug into the tube, not onto it
    The docs described payloads as mounting on adapters that clamp around the
    outside of the tube. They do not. The tube is a single uncut length sized
    for the mission, and payloads ride inside it: an adapter wraps the payload
    so it slides into the bore, anywhere along the length. A payload that is
    already a correct-diameter cylinder needs no adapter.
    This is the plug interface, not the sleeve one — new payload parts must
    reuse it. Also documents the two-gauge calibration workflow in the README.
2026-07-18 Split the wing adapter: clamping trim rig + glue-on flight variant
    The M3 clamp only earns its hardware while a payload's CG is being found.
    So the clamping adapter becomes reusable TOOLING (trim rig), and replicas
    fly a new hardware-free variant that is slid to the documented station and
    tacked with hot-glue fillets at the rims — lighter, cheaper, and in the
    spirit of a possibly single-use airframe. Each rim gets a 1.8 mm chamfered
    glue seat so the fillet keys into the plastic instead of a sharp corner.
    Sleeve, tabs, and spar sockets move to cad/lib/wing_adapter_common.scad,
    shared by both parts, so the wing-root interface cannot drift between the
    rig and the flight adapter. The refactor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
    [main_assembly.scad, wing_adapter.scad, wing_adapter.stl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]
2026-07-18 Show the glue-on flight adapter in the assembly render
    The README image should depict a finished airframe, and finished airframes
    fly the hardware-free variant — the clamping trim rig is bench tooling.
    [main_assembly.scad]
2026-07-19 Refine the wing: single rib row, rounded tip ribs, inset taped ailerons
    The servo rib now replaces the nearest standard rib in the row instead
    of doubling up beside it. New tip rib variant closes each panel: thicker,
    blind spar sockets the rod ends glue into (spar length now derives from
    tip_spar_socket), and a rounded outboard cap. Ribs inside the aileron
    span are a new TE-cropped variant so the aileron nests inside the
    planform; it mounts with a plain tape hinge along the top skin, written
    up in docs/control-system.md.
    Also pin render_scad.py's nixpkgs to nixos-26.05: the registry unstable
    has no cached openscad-unstable and its source build fails at link time.
    Noted in the openscad-revie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
    [control_surface.scad, design_params.scad, main_assembly.scad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]
2026-07-21 Add the verify gate: regen_all --check compares renders against committed artifacts
    Read-only commit gate grown out of regen_all.py rather than a parallel
    tool: it renders every part and the assembly to a temp dir and
    byte-compares against the committed STLs and main_assembly.png, flags
    orphaned STLs, and keeps the param and throw gates in front. Renders
    are byte-deterministic thanks to the pinned OpenSCAD, so equality is
    exact. The new verify skill documents it as the pre-commit step. The
    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
2026-07-21 Add CI (verify.yml) and a no-nix path for the whole toolchain
    Revives the verify gate from PR 2 with the piece that closed it fixed:
    CI no longer needs nix. Following the pourbot design workflow, CI
    installs the latest OpenSCAD snapshot AppImage and hands it to the
    scripts through the new OPENSCAD env var, which makes every script
    (render_scad.py and everything built on it) runnable without nix on
    any machine with an OpenSCAD binary. The scripts are stdlib-only
    Python, so no pip install is needed either. The pinned nix path stays
    the local default.
    Byte-identical renders only hold within one OpenSCAD build, so a full
    regen now records its build version in stl/openscad_version.txt and
    regen_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
2026-07-29 Promote wing span layout to design_params; add the wing_check gate
    The span layout (rib stations, servo/aileron/tip stations, aileron span)
    moves from main_assembly.scad into design_params.scad, making span a
    first-class tunable: resize the wing per mission and rod stock by editing
    the literals. Rib-local values that gained a second consumer move too
    (spar_x_pos, spar_socket_lift, servo_rib_thickness, tip_rib_flat,
    aileron_te_gap, aileron_arm_plane, aileron_arm_x_te).
    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
2026-07-29 Add the foam-skin cut template, SVG artifact pipeline, and wing build guide
    cad/wing_skin.scad develops the one-piece foam skin flat: a 2D line
    drawing (outline, LE fold, spar lines, rib-station glue lines, servo-arm
    slot, aileron corner cut-offs, 100 mm scale bar) exported to
    templates/wing_skin.svg in mm units for 1:1 printing. The developed
    lengths reuse the NACA surface functions from wing_rib.scad via use<>,
    so template and ribs cannot drift apart. This closes the control-system
    open item about the freehand servo-arm slot.
    regen_all.py gains SVG_PARTS: 2D templates render through the same
    run_one machinery as STLs, so temp-dir rendering, byte comparison in
    --check, the version self-ski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
2026-07-29 Add spar fit gauge, rib square jig, and skin cradle
    Calibration audit for the wing build found one uncalibrated fit: every
    rib and both adapter sockets trust spar_hole_d, but nothing measured it.
    calibration/spar_fit_gauge.scad prints three numbered blocks bracketing
    the current value, judged over a 12 mm engagement; the winning number
    goes back into design_params like the tube gauges.
    Two pieces of printed assembly tooling: rib_square_jig.scad rides both
    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
2026-07-29 Tile the skin template onto A4: print-ready PDF from any home printer
    The single-sheet SVG needs an A3 printer, which most homes lack.
    scripts/tile_template.py slices a template SVG into portrait A4 pages
    tiled along the span: 15 mm overlap at each seam, alignment crosses
    printed on both sides of every joint, and a per-page footer telling the
    builder to print at 100% and check the scale bar. The chord fits one
    page, so the wing template is three pages and two taped seams; the
    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
